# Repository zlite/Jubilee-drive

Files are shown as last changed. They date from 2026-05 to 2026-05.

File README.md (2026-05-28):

This is a low-cost pipette drive for the Jubilee lab automation frame, with a BOM of less than $40. It's an alternative to [this design](https://github.com/RicktheF22Raptor/jubilee-3D-Automatic-pipette-tool-), which has a BOM of around $300. That's too much!

The two are shown side-by-side here. The original design is on top, the cost-down redesign is below. The redesign retains the pipette's tip ejection mechanism.
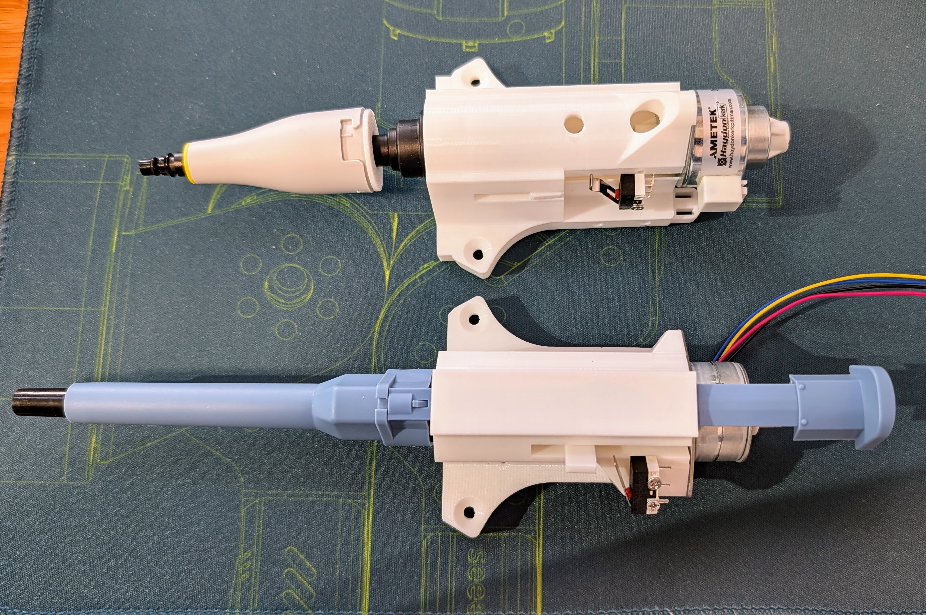
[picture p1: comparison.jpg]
comparison


**BOM:**

-- [Linear stepper motor ($14)](https://www.omc-stepperonline.com/25-2x15mm-pm-captive-linear-stepper-motor-0-5a-lead-1-22mm-0-048-travel-13-5mm-25ln48l01-334)

-- [Pipette (100-1000ul recommended - $25)](https://amzn.to/3Q2XR9Q)

-- [limit switch (optional)](https://amzn.to/3PLHGNV)

**Instructions**

Use the included tool with the pipette to unscrew the top:
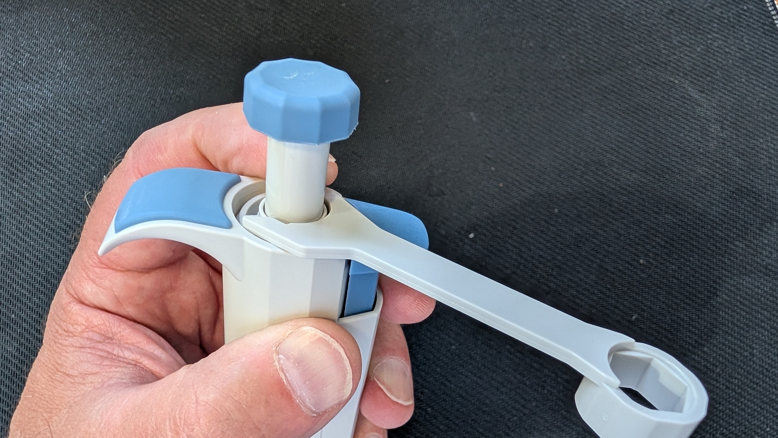
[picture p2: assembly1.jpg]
assembly1


Use the tool to lift the latch on the tip ejector rod, so you can pull out the tip
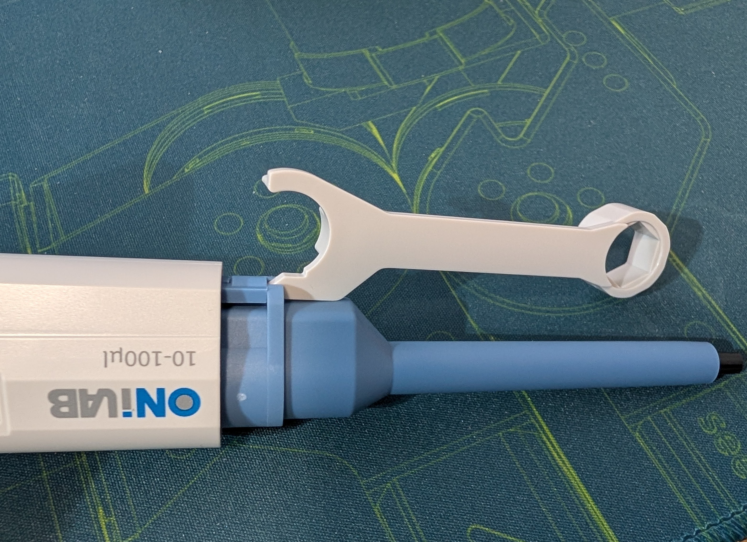
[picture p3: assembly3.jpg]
assembly3


Use the other side of the tool to unscrew the bottom:
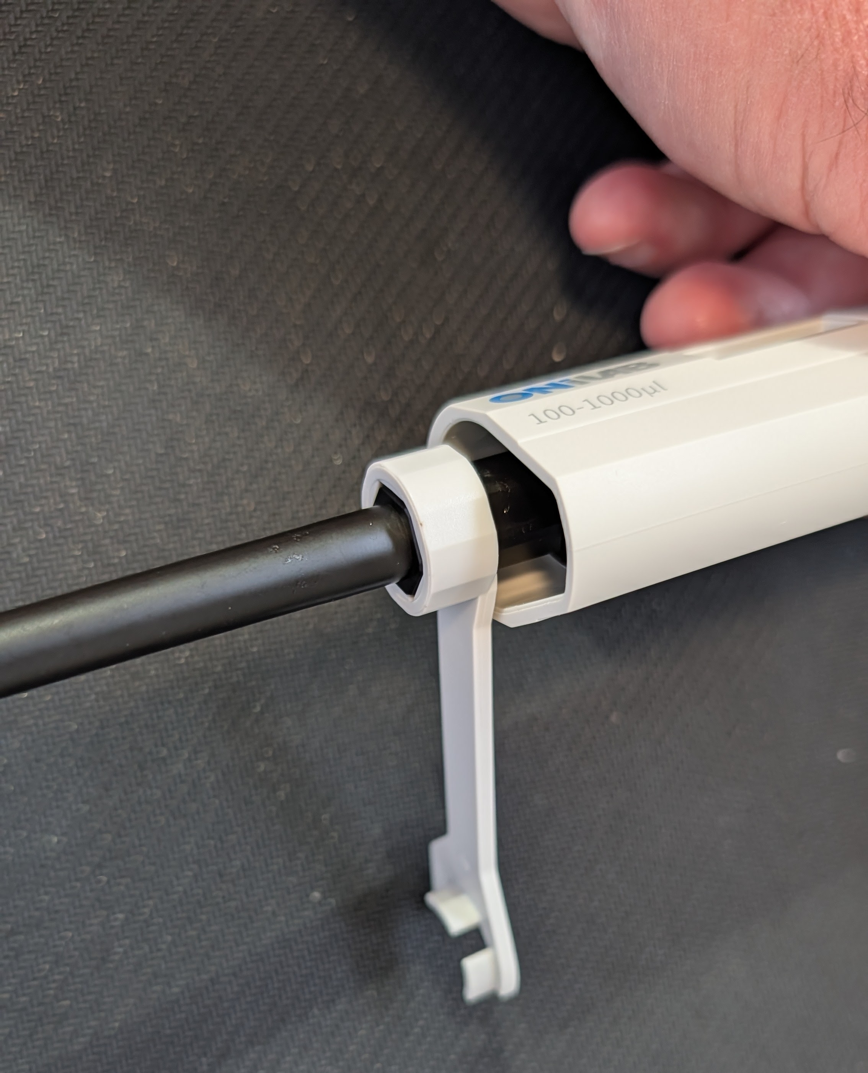
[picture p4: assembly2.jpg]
assembly2


You will end up with these parts:
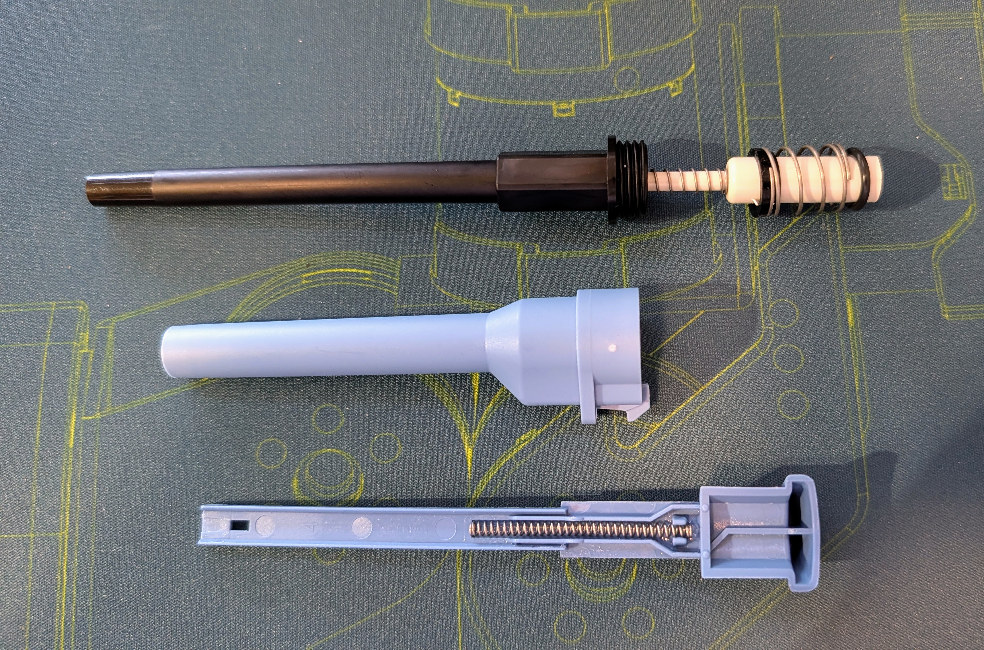
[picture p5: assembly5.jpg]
assembly5


Cut off the top of the piston tube, about 10mm up from the step, as shown here:
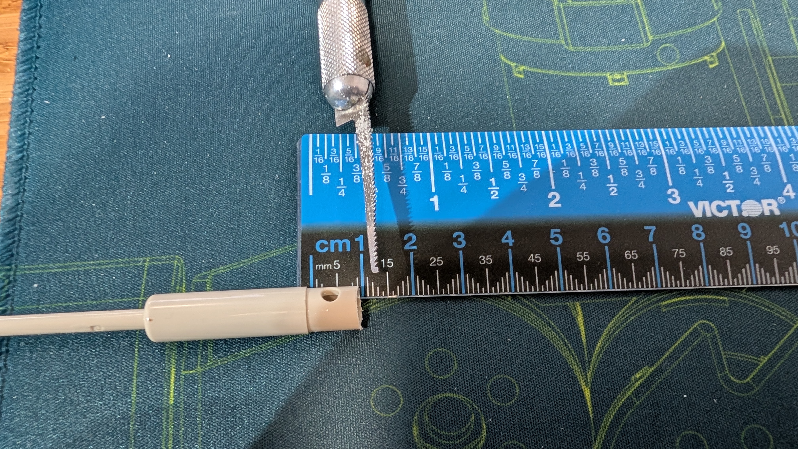
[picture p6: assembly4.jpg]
assembly4


Print out the two 3D-printed parts: [body](body.stl) and [connector](connector.stl).

Screw the connector onto the end of the stepper (push it in hard while turning so the the threads grab) and insert it into the piston tube, squeezing the split part, until it clicks into the holes
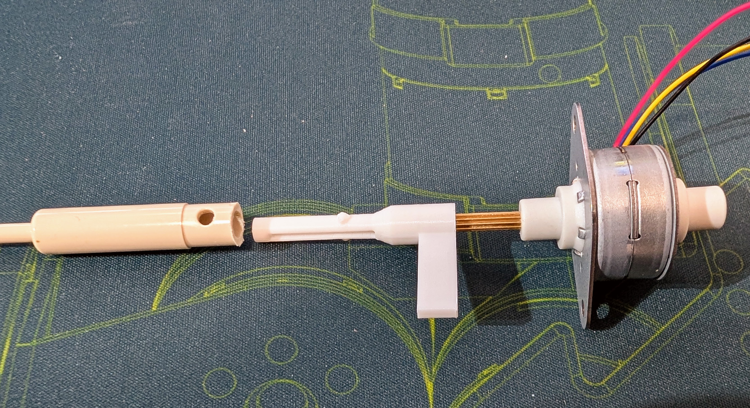
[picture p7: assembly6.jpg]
assembly6


Screw the stepper motor into the holes at top as well as the limit switch (if used) with M2 self-tapping screws and insert all the other parts as shown above.

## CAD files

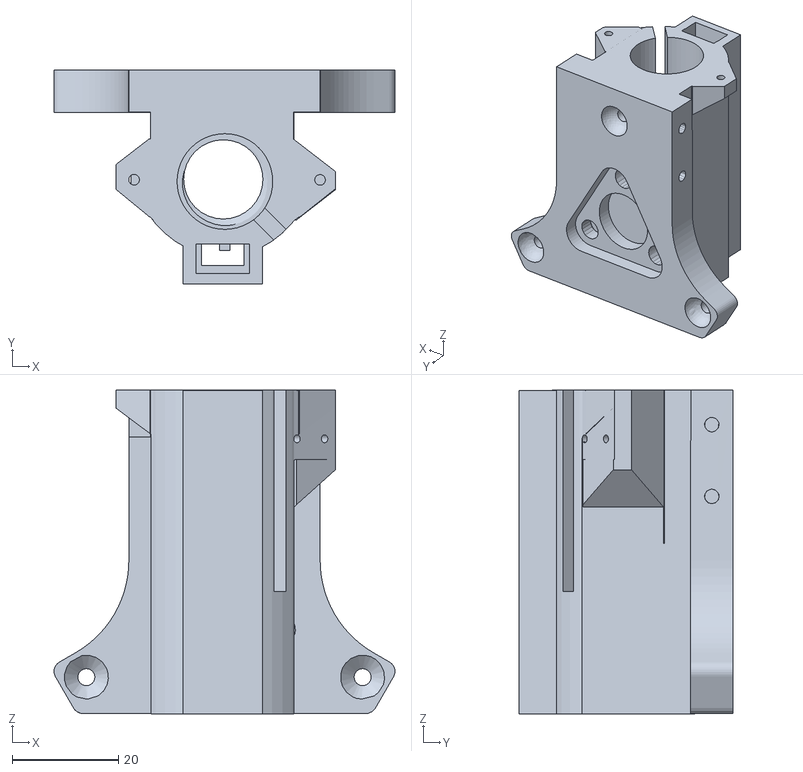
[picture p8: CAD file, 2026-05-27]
body.stl
64.1 x 40.3 x 60.9

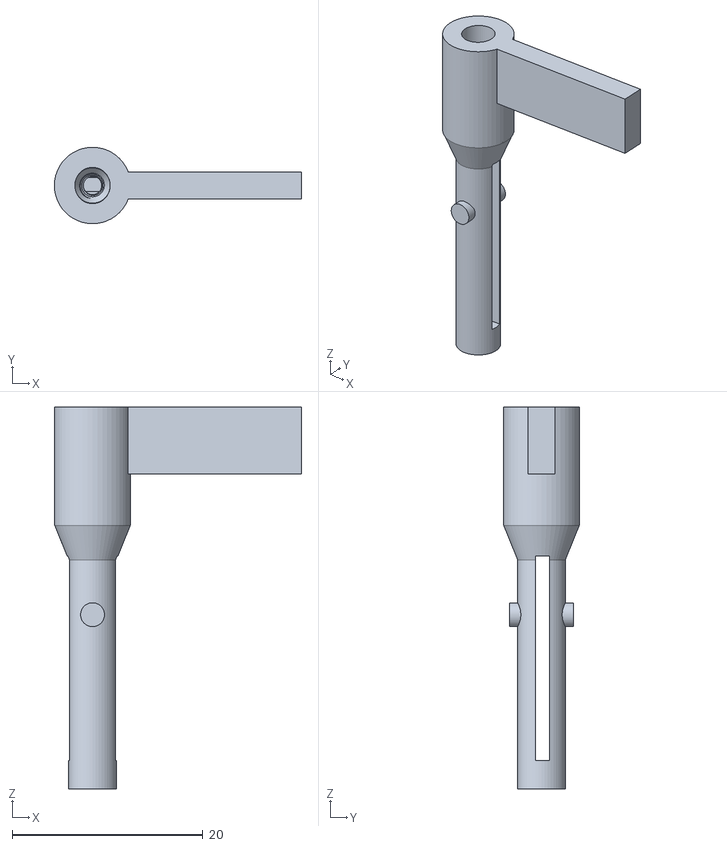
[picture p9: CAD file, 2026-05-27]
connector.stl
25.9 x 8.00 x 40.0

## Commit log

2026-05-21 Add README for low-cost pipette drive project
    Added detailed instructions and BOM for a low-cost pipette drive design.
2026-05-21 Fix image reference for assembly instructions
2026-05-22 Update README with redesign details
    Added a note about the redesign retaining the pipette's tip ejection mechanism.
2026-05-27 Tested with full stepper movement
    [body.stl, connector.stl]
2026-05-27 Update README for clarity on assembly instructions
